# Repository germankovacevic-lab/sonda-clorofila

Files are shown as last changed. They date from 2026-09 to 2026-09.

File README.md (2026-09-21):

# Proyecto SONDA — Fluorómetro DIY de clorofila-a y turbidez

**Dossier constructivo · Copernicus · versión 2026-09**

## Qué es esto

Un instrumento de mesa, portátil y de bajo costo, que mide **clorofila-a** (indicador de algas/cianobacterias) y **turbidez** en muestras de agua. Se toma una muestra del espejo de agua con un frasco, se vuelca en una **cubeta de vidrio**, se mete la cubeta en el aparato, y en ~3 minutos el aparato escribe los resultados en una tarjeta SD.

El principio es **fluorometría**: la clorofila-a, iluminada con luz azul (~430 nm), re-emite luz roja (~680 nm). Un sensor espectral mide esa luz roja: a más clorofila, más señal. La turbidez se estima con un segundo LED infrarrojo y la luz que dispersan las partículas en suspensión.

## Para qué lo queremos

Copernicus monitorea espejos de agua por satélite (Sentinel-2). El satélite estima clorofila desde el espacio; este aparato nos da el **dato de verdad medido en el agua** para calibrar y validar esas estimaciones. No necesita ser un instrumento de laboratorio certificado: necesita ser **repetible y consistente**.

## Qué diseño replicamos

Este dossier NO es un diseño propio: es la guía en castellano para construir el
**DockEye** del COAST Lab (EE.UU.), un diseño abierto y publicado, usando de
manual complementario el **fluorómetro del ENSSAT** (Francia, escuela de
fotónica).

**DockEye viene incluido en este repo** (`vendor/DockEye/`, licencia MIT —
firmware en `vendor/DockEye/Firmware/`, y el set imprimible listo para usar
en [`planos/`](planos/): gabinete v9 + tapa). El ENSSAT, por su tamaño, se
descarga aparte:

```bash
./descargar-fuentes.sh   # clona ENSSAT en vendor/ pineado al commit de referencia
```

Commits de referencia usados para este dossier (2026-09-21):

- DockEye: `aea70d69787ee7859948dcfca584f06a7d0c6c92` (2025-07-14)
- ENSSAT: `876ba0dcd2a57655762b38ec11ed856d72429feb` (2025-07-17)

**Ante cualquier duda, la fuente manda**: el código, los STL y los README de
`vendor/DockEye/` son el original. Este dossier traduce, ordena y localiza
(componentes conseguibles en Argentina), pero no inventa nada. Donde la fuente
no es clara, el punto está marcado **A VERIFICAR**.

## Mapa del dossier

| Doc | Contenido |
|---|---|
| [01-lista-de-materiales.md](01-lista-de-materiales.md) | Todos los componentes: qué son, dónde conseguirlos en Argentina, sustitutos |
| [02-armado.md](02-armado.md) | Conexiones (tabla de pines), soldadura, impresión 3D, ensamble |
| [03-firmware.md](03-firmware.md) | Cómo cargar el programa al ESP32 y verificar que todo responde |
| [04-protocolo-de-uso.md](04-protocolo-de-uso.md) | Cómo medir: muestra, blanco, registro, calibración |
| [05-pruebas-de-aceptacion.md](05-pruebas-de-aceptacion.md) | Checklist de entrega: qué tiene que demostrar el aparato terminado |
| [06-videos-y-recursos.md](06-videos-y-recursos.md) | Videos y recursos de apoyo por habilidad; el armado de la unidad #1 será filmado |
| [planos/](planos/) | El set imprimible completo: **gabinete v9** (DockEye, MIT) + **tapa v1** (diseño: [Esteban Kovacevic](https://github.com/EstebanKovacevic), CC BY-SA) |

## Resumen del hardware (arquitectura)

```
                      ┌──────────────────────────┐
  USB-C / batería ───►│ ESP32-S3 (cerebro)       │
                      │  · corre el firmware     │
                      └────┬──────────┬──────────┘
                     I²C   │          │ I²C + SPI
              ┌────────────▼───┐  ┌───▼──────────────────┐
              │ AW9523         │  │ Adalogger            │
              │ driver de LEDs │  │ reloj (RTC) + SD     │
              └──┬─────────┬───┘  └──────────────────────┘
                 │         │
          LED azul       LED infrarrojo        ┌─────────────┐
          430 nm         910 nm                │ AS7341      │
             │              │                  │ sensor      │
             └──────► CUBETA ◄─── a 90° ──────►│ espectral   │
                    (vidrio, 10 mm)            └─────────────┘
                 dentro de gabinete impreso en 3D, oscuro
```

Todo va montado en el gabinete impreso en 3D de DockEye, que sostiene la cubeta
con los LEDs de un lado y el sensor **a 90 grados** (por eso la cubeta debe
tener las 4 caras transparentes).

## Presupuesto orientativo (2026-09, estimativo)

- **Vía local + sustitutos (ML/tiendas de electrónica):** ARS 150.000–280.000 aprox., según qué se consiga local y qué llegue de China por ML.
- **Vía importación de originales Adafruit (DigiKey/Mouser/courier):** ~USD 60–80 en partes + envío e impuestos; los LEDs Thorlabs originales suman ~USD 40–60 más.
- Detalle componente por componente en [01-lista-de-materiales.md](01-lista-de-materiales.md).

## Contacto técnico

Cualquier ambigüedad de la fuente está marcada **A VERIFICAR** en cada doc.
Antes de resolverla por las suyas, consultar con quien encargó el trabajo
(las decisiones de sustitución de componentes ópticos afectan la calibración).

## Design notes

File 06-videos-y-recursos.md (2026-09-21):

# 06 · Videos y recursos de apoyo

## ¿Hay video-tutorial del aparato?

**Todavía no — y va a haber.** Ni DockEye ni ENSSAT publicaron video de armado
(verificado 2026-09). Este dossier escrito es hoy la guía más completa que
existe del instrumento. **El armado de la primera unidad va a ser filmado y
publicado acá**, paso a paso, como video-tutorial completo en castellano.
Si estás construyendo y te trabás en un paso concreto, escribinos:
hola@copernicus.com.ar — lo destrabamos y de paso mejora el dossier.

## Recursos por habilidad

El armado no usa ninguna técnica exótica: se descompone en cuatro habilidades
estándar del mundo maker, cada una con muchísimo material en español. Por cada
una: una guía escrita de referencia + qué buscar en YouTube.

### 1. Soldar tiras de pines a los módulos
- Búsqueda YouTube: `como soldar pines header arduino`
- Es la soldadura más básica que existe (pin pasante, pad grande). Regla del
  doc 02: soldadura brillante y cónica, sin puentes entre pines vecinos.

### 2. Programar el ESP32 con Arduino IDE
- Guía escrita (referencia clásica en español): https://www.luisllamas.es/como-programar-esp32-con-el-ide-de-arduino/
- Curso Prometec (texto + video): https://www.prometec.net/02-instalando-el-entorno-arduino-y-el-pluggin-esp32/
- Búsqueda YouTube: `instalar ESP32 arduino IDE español`
- Después seguir el doc 03 de este dossier (tiene los pasos específicos).

### 3. Conectar módulos I²C (sensor, RTC, driver)
- Guía escrita: https://www.luisllamas.es/arduino-i2c/
- Búsqueda YouTube: `bus I2C arduino explicado español`
- Lo específico nuestro (qué pin va con qué) está en las tablas del doc 02 —
  no hace falta entender el protocolo, solo conectar según tabla.

### 4. Imprimir el gabinete 3D
- El set imprimible completo está en `planos/`: `gabinete-dockeye-v9.stl` + `tapa-v1.stl`.
- Búsqueda YouTube: `imprimir STL cura tutorial español`
- Sin impresora propia: cualquier servicio de impresión 3D lo cotiza con el
  STL (parámetros en el doc 02: PLA/PETG negro opaco, relleno ≥50%).

## Bibliografía del método (para quien quiera el fundamento)

- Leeuw, Boss & Wright (2013) — fluorómetro de fitoplancton con electrónica
  de bajo costo, validado contra instrumentos comerciales: doi:10.3390/s130607872
- Lopin (2024) — sensores AS726x/AS7341 para clorofila con regresión PLS:
  github.com/KyleLopin/asm_chloro_test

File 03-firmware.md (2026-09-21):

# 03 · Firmware: carga y verificación

> Fuente: `vendor/DockEye/Firmware/Open_Fluorometer/DockEye.ino` y
> `vendor/DockEye/Firmware/README.md`. El firmware es UN solo archivo .ino.

## 1. Qué hace el firmware (para entender qué esperar)

Al encender, el aparato ejecuta **una** secuencia completa y se queda quieto:

1. Inicializa sensor AS7341, RTC y driver AW9523. Si alguno no responde, **se frena** e imprime el error por el puerto serie.
2. Crea/abre `Test.csv` en la SD y escribe el encabezado.
3. Parpadea el LED indicador 2 veces → **fase clorofila**: enciende el LED azul 60 segundos, midiendo y grabando continuamente los 10 canales del sensor.
4. Parpadea 3 veces → **fase turbidez**: enciende el LED infrarrojo 60 segundos, ídem.
5. Escribe en la SD un bloque `SUMMARY` con: promedio F8 con LED azul, promedio F8 con LED IR (fondo), la resta, y la clorofila-a calibrada con la ecuación `chla = 0,1332 × diff − 1,7127` (⚠️ esa ecuación es la calibración del aparato de ELLOS: para el nuestro se reemplaza tras calibrar — doc 04).
6. Queda en bucle infinito hasta que se lo apague y prenda de nuevo.

Cada medición vuelca por el puerto serie (9600 baudios) una barra de progreso y los valores crudos: eso es lo que se usa para verificar.

## 2. Preparar el entorno (Arduino IDE en castellano)

1. Instalar **Arduino IDE 2.x** desde arduino.cc (Archivo → Preferencias → Idioma: Español).
2. Agregar soporte ESP32: Archivo → Preferencias → *URLs adicionales de gestor de placas*, pegar:
   `https://espressif.github.io/arduino-esp32/package_esp32_index.json`
3. Herramientas → Placa → Gestor de placas → buscar **esp32** (por Espressif Systems) → Instalar (versión 3.x).
4. Instalar librerías: Herramientas → Administrar bibliotecas, buscar e instalar:

| Librería | Autor | Nota |
|---|---|---|
| **Adafruit AS7341** | Adafruit | instala solas sus dependencias (BusIO, Sensor) — aceptar "Instalar todas" |
| **Adafruit AW9523** | Adafruit | solo si se usa el AW9523 |
| **RTClib** | Adafruit | maneja PCF8523 y DS3231 |
| **SdFat - Adafruit Fork** | Bill Greiman | ⚠️ elegir el **fork de Adafruit**, no el SdFat original |

   El repo no fija versiones exactas (**A VERIFICAR** solo si algo no compila: probar la última estable de cada una; el firmware es simple y usa APIs básicas).

5. Selección de placa:
   - Feather original: Herramientas → Placa → esp32 → **Adafruit Feather ESP32-S3 2MB PSRAM** (o la variante que corresponda al modelo comprado).
   - Devkit genérico: **ESP32S3 Dev Module**.
   - En ambos: `USB CDC On Boot: Enabled` (para que se vea el monitor serie por USB).

## 3. Ajustes al .ino según el hardware armado

Abrir `vendor/DockEye/Firmware/Open_Fluorometer/DockEye.ino` y guardarlo como copia de trabajo (ej. `firmware-sonda/sonda.ino` — no editar el vendor). Ajustes:

### 3.1 Si se armó la versión original (Feather+Adalogger+AW9523)
Nada que tocar. Flashear tal cual.

### 3.2 Si se usa RTC DS3231 en vez del Adalogger
```cpp
// línea 8:  RTC_PCF8523 rtc;   →
RTC_DS3231 rtc;
```
y más abajo, `rtc.initialized()` no existe para DS3231: reemplazar ese chequeo por `rtc.lostPower()`.

### 3.3 Si el CS de la microSD no es el pin 10
```cpp
// línea 20: const int SD_CHIP_SELECT = 10;  →
const int SD_CHIP_SELECT = <GPIO elegido>;
```

### 3.4 Si NO se usa AW9523 (LEDs por GPIO + transistor)
Hay que reemplazar el manejo de LEDs: quitar `Adafruit_AW9523.h`, el objeto `aw`, y las llamadas `aw.pinMode/aw.analogWrite`, por `pinMode(GPIO, OUTPUT)` y `digitalWrite(GPIO, HIGH/LOW)` sobre los GPIO elegidos para LED azul, LED IR y LED indicador. Son ~6 puntos de edición, todos evidentes buscando `aw.` en el archivo. Mantener la lógica idéntica (mismos tiempos, mismas fases).

### 3.5 Para uso en campo sin PC conectada
El `setup()` arranca con:
```cpp
while (!Serial) { delay(1); }
```
Eso **espera a que haya un monitor serie abierto**: conectado a un power bank, puede quedarse esperando para siempre. Para uso autónomo, comentar esas líneas (o encerrarlas en un timeout). **A VERIFICAR en banco**: probar el aparato con power bank y confirmar que arranca solo. Para todas las pruebas del doc 05, dejarlo como está (se trabaja con la PC conectada).

## 4. Flasheo

1. Conectar la placa por USB-C (cable de datos).
2. Seleccionar el puerto: Herramientas → Puerto (aparece al conectar; en Windows es COMx, en Mac /dev/cu.usbmodem…).
3. Botón **Subir** (flecha →). Si la placa no entra sola en modo de programación: mantener **BOOT**, tocar **RESET**, soltar BOOT, reintentar.
4. Éxito = "Hard resetting via RTS pin..." o similar, sin errores rojos.

## 5. Primera verificación (con el monitor serie)

Herramientas → Monitor Serie, **9600 baudios**. Apretar RESET en la placa. Debe verse, en orden:

1. Ningún mensaje de error. Los errores posibles y su significado:
   - `Could not find AS7341` → revisar cableado I²C del sensor (SDA/SCL invertidos es el clásico) o dirección.
   - `Couldn't find RTC` → cableado I²C del RTC o pila faltante.
   - `AW9523 not found? Check wiring!` → ídem para el driver.
   - `Error opening file!` → SD ausente, mal formateada (usar FAT32) o CS incorrecto.
2. `AW9523 found!` (si aplica).
3. `Begin chlorophyll measurements.` + LED azul encendido (se ve por la ranura de la cubeta si la tapa está abierta) + barra de progreso `Chlorophyll-a: [###...] 42%` + líneas `Raw F8: <número>`.
4. Al minuto: `End chlorophyll measurements.` → `Begin turbidity measurements.` + LED IR encendido (⚠️ el IR es invisible al ojo; se ve **con la cámara del celular**, que lo capta violáceo) + líneas `Raw NIR: <número>`.
5. Al final: bloque `==== FINAL AVERAGE RESULTS ====` con los promedios.

6. Apagar, sacar la microSD, abrirla en la PC: debe existir `Test.csv` con encabezado, ~2 minutos de filas de datos y el bloque `SUMMARY` al final. ⚠️ El firmware **agrega** al mismo `Test.csv` en cada corrida: para cada ensayo nuevo conviene borrar o renombrar el archivo previo.

## 6. Ajuste del RTC (fecha y hora)

El firmware original **no pone en hora el RTC** (solo avisa si no corre). Para ponerlo en hora una única vez: cargar el ejemplo `RTClib → pcf8523` (o `ds3231`) del IDE, que ajusta el reloj a la hora de compilación, y después volver a flashear el firmware de la sonda. Con la pila puesta, la hora se conserva.

## 7. Parámetros del sensor (no tocar sin motivo)

El firmware fija: `ATIME=255`, `ASTEP=999`, ganancia `256X` → tiempo de integración ≈ 0,7 s por lectura. Son los valores con los que DockEye calibró. Si el sensor **satura** (valores clavados en 65535) o queda sin señal, se ajusta la ganancia — pero eso invalida comparaciones con datos previos: anotar SIEMPRE cualquier cambio en la hoja del instrumento (el CSV graba ATIME/ASTEP/GAIN en cada fila, lo que permite auditar).

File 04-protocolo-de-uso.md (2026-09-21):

# 04 · Protocolo de uso y calibración

> Fuente: procedimiento de extracción y estándares de
> `vendor/DockEye/Procedures/Chlorophyll a extraction/README.md`, guía de
> calibración de `vendor/Chlorophyll-Fluorometer/calibration.md` (ENSSAT) y
> scripts de `vendor/DockEye/Data Analysis/`.
>
> Este doc lo usa quien opere el instrumento. El constructor solo necesita
> entenderlo por arriba + ejecutar las pruebas del doc 05.

## 1. Regla de oro

**Cubetas de VIDRIO o CUARZO, nunca plástico.** Los estándares de calibración
van en acetona al 80%, que disuelve el plástico. Y una cubeta atacada por
solvente queda opaca → basura. Todas las cubetas del kit son de vidrio/cuarzo
con 4 caras transparentes.

## 2. Medición de rutina (muestra de campo)

### 2.1 Toma de muestra
1. Tomar agua sub-superficial (~20–30 cm de profundidad) del espejo de agua, en frasco limpio y opaco o envuelto (la clorofila se degrada con luz y calor).
2. Rotular: fecha, hora, punto GPS, quién.
3. Medir lo antes posible (ideal < 2 h; mantener fresco y a oscuras hasta medir).

### 2.2 Medición
1. Homogeneizar la muestra (invertir el frasco suavemente 10 veces; no agitar violento, hace burbujas).
2. Enjuagar la cubeta 2 veces con la propia muestra; llenar a ~3/4. **Sin burbujas** en las caras ópticas; secar el exterior con papel suave (huellas y gotas desvían luz).
3. Insertar la cubeta en el gabinete, cerrar la tapa.
4. Encender el aparato (o RESET). Corre solo: 2 parpadeos → 60 s de LED azul → 3 parpadeos → 60 s de LED IR → resumen. Total ~2,5 min.
5. Apagar, retirar cubeta, enjuagar con agua destilada.

### 2.3 Blanco
En cada tanda de mediciones (mínimo al inicio y al final), correr una medición
idéntica con **agua destilada**. Ese valor es el cero del día y baja junto con
los datos.

### 2.4 Registro
- Los datos quedan en `Test.csv` de la microSD. **Renombrar el archivo tras cada corrida** (ej. `2026-09-21_laguna-X_p1.csv`), porque el firmware agrega al mismo archivo.
- Llevar planilla paralela: fecha/hora, punto, blanco del día, archivo asociado, observaciones (color del agua, clima).
- El valor que interesa: en el bloque `SUMMARY`, la resta `Chl − Turb F8` (señal de fluorescencia corregida por fondo) y la `Calibrated Chlorophyll-a` **solo si ya se cargó nuestra ecuación de calibración** (ver §3.4).

## 3. Calibración (resumen)

La calibración convierte "cuentas" del sensor en µg/L. Se hace al construir el
aparato, y se repite si se cambia cualquier componente óptico o parámetro del
sensor.

### 3.1 Preparar extracto de clorofila (fuente: espinaca)
Del procedimiento DockEye:
1. Picar y pesar ~4 g de hojas de espinaca fresca.
2. Moler en mortero con 5–10 mL de acetona fría hasta que no queden trozos visibles.
3. Pasar a frasco de vidrio ámbar con 20 mL de acetona al 80%.
4. Sonicar 30 min en baño de hielo (si no hay sonicador: **A VERIFICAR** — DockEye no da alternativa; en la práctica reposo prolongado en frío y oscuridad extrae igual, con menor eficiencia).
5. Centrifugar 5 min a 3000 rpm (o dejar decantar y filtrar) y quedarse con el líquido claro (sobrenadante).
6. La concentración real del extracto madre se determina contra un instrumento de referencia (laboratorio o fluorómetro comercial). **Este paso requiere un tercero con instrumento calibrado** — es el único eslabón que no se resuelve con el kit.

### 3.2 Estándares
Diluir en acetona al 80% para obtener 5 puntos: **100, 50, 20, 10 y 5 µg/L**
(cada uno se logra diluyendo el anterior: 2×, 2,5×, 2×, 2×).

### 3.3 Medir la curva
1. Medir blanco (acetona 80% sola).
2. Medir cada estándar de menor a mayor concentración, con el protocolo normal (§2.2), enjuagando la cubeta con el estándar siguiente entre puntos.
3. En planilla (Excel/LibreOffice): graficar señal (promedio F8 con LED azul, menos fondo) vs. concentración. Ajustar recta: `señal = a × concentración + b`. Debe dar R² > 0,95; si no, revisar burbujas, luz externa, cubeta sucia.

### 3.4 Cargar la calibración al firmware
Invertir la recta y reemplazar en el .ino (línea ~114):
```cpp
float calibrated_chla = 0.1332 * diff - 1.7127;  // ← ecuación de DockEye, NO la nuestra
```
por los coeficientes propios (`chla = (diff − b) / a`). Anotar fecha de
calibración y coeficientes en la hoja del instrumento. Re-flashear.

> Nota: los números 0,1332 y −1,7127 que trae el código son la calibración del
> prototipo de COAST-Lab. **Sin recalibrar, las lecturas "calibradas" de nuestro
> aparato no son confiables** — sí lo son las cuentas crudas y sus diferencias.

### 3.5 Turbidez
DockEye no publica protocolo de calibración de turbidez (el canal NIR se usa
sobre todo como fondo para la clorofila). Si se quiere turbidez en NTU:
calibrar con estándares de formazina o suspensiones caseras validadas —
**A VERIFICAR / fase 2**, no bloquea la entrega.

## 4. Mantenimiento

- Cubetas: lavar con agua destilada tras cada uso; guardar secas y envueltas. Nunca cepillar por dentro con nada abrasivo.
- No dejar muestras/estándares dentro del aparato.
- Acetona: manipular con ventilación, lejos de fuentes de calor; guardar en frasco de vidrio rotulado.
- Revisar cada tanto que el gabinete siga sellado a la luz (prueba de linterna del doc 02 §5).

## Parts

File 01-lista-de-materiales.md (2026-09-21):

# 01 · Lista de materiales (BOM)

> Precios y disponibilidad **verificados 2026-09-21** publicación por publicación
> en MercadoLibre Argentina (sesión en vivo). Donde dice "verificado" es el precio
> de un listing concreto de ese día. Los part numbers del diseño original salen
> del README de `vendor/DockEye/`.
>
> Regla general: **el sensor AS7341 y el conjunto óptico son el corazón del
> instrumento — no escatimar ahí.** En el resto (micro, SD, RTC, cables) los
> genéricos sirven perfecto.

## A. Electrónica principal

### A1. Microcontrolador — ESP32-S3

- **Función:** cerebro del aparato; corre el firmware, habla con los sensores, escribe la SD.
- **Original:** Adafruit ESP32-S3 Feather (Adafruit **#5477**, ~USD 17,50 en adafruit.com).
- **En Argentina:** el Feather original de Adafruit **no se consigue local** (ML solo trae otros Feather a >$190.000). Lo que sí abunda:
  - Placa genérica **ESP32-S3 DevKitC / NodeMCU ESP32-S3** (WROOM-1, USB-C) — verificado 2026-09-21: **$18.644** (listing "Placa De Desarrollo Esp32 S3 N16r8 Wifi Bluetooth 2 Usb-c", stock local, llega hoy) · alternativa **$20.990** ("Nodemcu ESP32 S3 44 Pines Usb C", HobbyTronica 4.9, local).
- **Sustituto aceptable:** SÍ, cualquier devkit ESP32-S3 con USB nativo.
  - *Qué se pierde:* el formato Feather (el gabinete STL de DockEye está pensado para apilar Feather + Adalogger; con un devkit genérico la electrónica va montada aparte, ver 02-armado) y el cargador de batería LiPo integrado (se reemplaza con un power bank USB).
  - *Qué NO se pierde:* nada eléctrico. El firmware usa I²C + SPI estándar; el fabricante del original avisa que solo probó el S3 MINI-1, así que **cualquier variante requiere la prueba de humo del doc 05 igual**.
- ⚠️ El firmware original usa el pin **10** como chip-select de la SD; en un devkit genérico elegir un GPIO libre y ajustar una línea del firmware (ver 03-firmware).

### A2. Datalogger — RTC + ranura microSD

- **Función:** reloj de tiempo real (fecha/hora de cada medición) + tarjeta SD donde queda el CSV con los datos.
- **Original:** Adafruit Adalogger FeatherWing (Adafruit **#2922**): RTC **PCF8523** + slot microSD, se apila sobre el Feather.
- **En Argentina:** no se consigue local. Sustituto de dos módulos, ambos ubicuos en ML:
  - **Módulo lector microSD SPI** (genérico) — verificado 2026-09-21: **$2.799** (listing "Modulo Lector De Tarjetas Micro Sd" UNIBOT, local, llega hoy) · $3.059 Starwarecomar · $4.999 HobbyTronica.
  - **Módulo RTC DS3231** (I²C, con pila) — verificado 2026-09-21: **$6.999** (listing "Modulo Rtc Ds3231 Alta Precision Eeprom 24c32 c/pila", HobbyTronica 4.9, local, llega hoy) · $5.399 Educabot (sin confirmar pila).
- **Sustituto aceptable:** SÍ, con un cambio de UNA línea en el firmware: `RTC_PCF8523` → `RTC_DS3231` (la librería RTClib soporta ambos; ver 03-firmware). El DS3231 es incluso más preciso que el PCF8523.
- También: **tarjeta microSD** clase 10, 8–32 GB (ARS 8.000–15.000, cualquier marca conocida).

### A3. Driver de LEDs — AW9523

- **Función:** expansor I²C de 16 pines que enciende/apaga y regula los LEDs con corriente constante, comandado por el ESP32. El firmware original lo usa tal cual (`Adafruit_AW9523`).
- **Original:** Adafruit AW9523 breakout (Adafruit **#4886**, ~USD 4,95).
- **En Argentina:** **NO se consigue** — re-verificado 2026-09-21: la búsqueda "aw9523" en ML devuelve 84 resultados pero **ninguno es el chip** (todo repuestos de notebook y herramientas). Ausencia confirmada. Opciones:
  1. **Importarlo** (Adafruit/DigiKey/Mouser, o pedido puntual a importador tipo CDR Electrónica, cdronline.com.ar — cotizan a pedido). Es chico y barato: conviene sumarlo al mismo pedido que cualquier otra cosa que se importe. **← Recomendado: mantiene el firmware original sin tocar.**
  2. **Sustituto local:** manejar cada LED directo desde un GPIO del ESP32 con un transistor NPN (2N2222/PN2222, <ARS 1.000) + resistencia limitadora — es exactamente lo que hace el diseño ENSSAT (`vendor/Chlorophyll-Fluorometer/hardware/components.md`).
     - *Qué se pierde:* la regulación de corriente constante del AW9523 (la intensidad del LED queda atada a la estabilidad de la fuente → algo más de deriva entre mediciones) y hay que **modificar el firmware** (reemplazar las llamadas `aw.analogWrite(...)` por control de GPIO; ver 03-firmware). Para un instrumento que se calibra contra estándares, es tolerable, pero la opción 1 es más fiel al original.

### A4. Sensor espectral — AS7341 ⭐ (el corazón, sin sustituto)

- **Función:** sensor de 11 canales que mide la luz por bandas: el canal **F8 (680 nm)** capta la fluorescencia de la clorofila y el canal **NIR (910 nm)** la dispersión por turbidez.
- **Original:** Adafruit AS7341 breakout (Adafruit **#4698**, ~USD 15,95).
- **En Argentina — verificado 2026-09-21:** SÍ hay, casi todo envío internacional desde China (2–4 semanas):
  - **$19.752** (listing "Módulo Sensor As7341 11 Canales For Medición", China) · $18.076 ("Módulo Sensor Del Espectrómetro De Color Visible", China).
  - Clon del breakout Adafruit ("As7341 Sensor De Luz De 10 Canales Placa Divisora Stemma"): **$22.665–24.276** (China).
  - Única opción aparentemente con stock local: "As7341 Módulo De Sensor De Espectrómetro" a **$139.998** (6 cuotas, envío gratis) — solo si el plazo de China es inaceptable.
- **Sustituto aceptable: NO.** Todo el firmware y la calibración de DockEye dependen de este chip exacto. Cualquier módulo que traiga el chip **AS7341** sirve (el chip es el mismo AMS); lo que cambia entre módulos es solo el conector.
- ⚠️ Comprar **dos** si el presupuesto lo permite: es el componente más difícil de reponer rápido si uno viene fallado.

### A5. LED de excitación azul — 430 nm

- **Función:** ilumina la muestra para excitar la clorofila-a (pico de absorción ~430 nm).
- **Original:** Thorlabs **LED430L** (LED 430 nm, encapsulado 5 mm, ~USD 40–60 + envío internacional caro — Thorlabs no vende barato ni rápido a Argentina).
- **En Argentina:**
  - **Elumiled** — verificado 2026-09-21: **$5.603/u** (listing "Led 3w Azul 420-430nm Epileds Estrella Predisipadora Elumiled", local) · x2 $8.810 · x5 $18.434. Ojo: es formato **estrella 3 W con predisipadora**, no 5 mm — en ML no apareció 430 nm en encapsulado 5 mm; el estrella funciona (más potencia, requiere limitar corriente y adaptar la montura del gabinete). **← Primera opción.**
  - Fallback azul royal — verificado 2026-09-21: **$8.590 x10** ("X10 Led Epiled Azul Profundo 440nm 3 Watts", local, llega mañana) · 10 W 445–450 nm $14.999.
- **Sustituto aceptable:** SÍ, con matices:
  - Un 425–435 nm local (Elumiled) es sustituto pleno: misma zona de excitación.
  - Un 445–450 nm también **funciona** (la clorofila absorbe fuerte en toda esa banda) pero con eficiencia de excitación algo menor → menos señal → la pendiente de calibración cambia. **No es problema porque cada aparato se calibra individualmente** (doc 04), pero hay que anotar la longitud de onda usada en la hoja del instrumento.
  - ⚠️ NO usar LED "azul común" sin especificación (suelen ser 465–470 nm, ya lejos del pico).
- **A VERIFICAR al comprar:** que el datasheet/publicación declare la longitud de onda dominante.

### A6. LED infrarrojo — 910 nm

- **Función:** ilumina la muestra en infrarrojo; las partículas en suspensión dispersan esa luz hacia el sensor → estimación de turbidez (y de fondo para restar a la señal de clorofila).
- **Original:** Thorlabs **LED910L** (910 nm, 5 mm).
- **En Argentina:** los IR de 5 mm ubicuos son de **940 nm** — verificado 2026-09-21: **$2.080 x5** (listing "X5 Led 5mm Infrarrojo Ir-led Emisor 940nm", local, llega mañana) · x10 $6.460 Htec, llega hoy. ⚠️ En la misma búsqueda hay **fototransistores/receptores** 940 nm al mismo precio: comprar el **EMISOR**.
- **Sustituto aceptable:** SÍ — LED IR **940 nm** ó **850 nm** de 5 mm.
  - *Qué se pierde:* el canal NIR del AS7341 está centrado en 910 nm; a 940 nm el sensor lo ve con menos sensibilidad (a 850 nm también, del otro lado). Menos señal de turbidez → se compensa en calibración. **A VERIFICAR** en banco: que con agua turbia (unas gotas de leche en agua) el canal NIR responda claramente sobre el fondo (prueba incluida en doc 05).

### A7. Pasivos y conexión

| Ítem | Para qué | Dónde / precio aprox. |
|---|---|---|
| Protoboard 830 pts + 40 cables dupont | montar módulos y LEDs | verificado 2026-09-21: $17.637 (kit, local) |
| Cables dupont M-H x40 30 cm | conexiones I²C y alimentación | verificado 2026-09-21: $4.133 (CANDYHO, local) |
| Tiras de pines macho + hembra | soldar a los módulos | ARS 1.000–3.000 |
| Resistencias (kit x100 metal film 1% 1/4 W, 10 valores) | limitadora de LEDs (si no se usa AW9523) | verificado 2026-09-21: $4.500 (Micro Minds, local, llega hoy) |
| Transistores PN2222A | driver de LED alternativo (solo opción A3-2) | verificado 2026-09-21: $2.840 x10 ("Kit X10 Pn2222a", local, llega mañana) |
| Cable USB-C **de datos** | flasheo y alimentación | ARS 4.000–10.000 (verificar que sea de datos, no solo carga) |
| Power bank USB 5 V | uso en campo sin PC | ARS 20.000–40.000 (opcional) |

## B. Óptica y muestras

### B1. Cubetas — VIDRIO o CUARZO, 4 caras transparentes ⭐

- **Función:** contienen la muestra. El LED entra por una cara y el sensor mira por la cara **a 90°** → las **4 caras deben ser transparentes** (las cubetas de espectrofotómetro comunes tienen solo 2 caras pulidas: **NO sirven**).
- **Material: vidrio o cuarzo, NUNCA plástico.** La calibración usa acetona (disuelve el plástico) y los solventes arruinan la cubeta y contaminan la muestra.
- **Original:** cubetas de vidrio para fluorometría, paso óptico 10 mm (DockEye las compra en Amazon, baratas).
- **En Argentina — verificado 2026-09-21:** todo envío internacional China (2–4 sem.):
  - **$17.377 el pack de 4** (listing "4 Celdas Cúbicas De Cuarzo 3.5ml 10mm", China) — mejor valor: cubre blanco + muestra + 2 repuestos en una compra.
  - Packs de 2: $18.678–24.633 ("Pack De 2 Cubetas De Cuarzo Ópticas 10mm").
  - (Proveedores locales de laboratorio tipo Instrumental Pasteur: ~ARS 197.000 la pieza — evitar salvo urgencia.)
- **A VERIFICAR al comprar:** confirmar con el vendedor que las 4 caras son pulidas/transparentes ("cubeta para **fluorescencia**", no "para espectrofotómetro"). Comprar **al menos 4** (blanco, muestra, repuesto x2).

### B2. Consumibles de calibración

(los usa quien calibra, no necesariamente el constructor — ver doc 04)

| Ítem | Para qué | Dónde |
|---|---|---|
| Acetona pura (p.a. o al menos >99%) | extracción de clorofila y estándares | ⚠️ verificado 2026-09-21: en ML solo hay removedores cosméticos con acetona — la p.a. **se compra en droguería física** (Cicarelli/local), ~ARS 8.000–20.000/litro |
| Alcohol etílico 96% (alternativa de extracción) | extracción de clorofila | verificado 2026-09-21: $18.600 bidón 5 L ("Alcohol Etilico 96% Bidon 5 Litros", local, llega hoy) |
| Agua destilada | blancos y diluciones | ferretería/farmacia, ARS 2.000–5.000 x5 L |
| Espinaca fresca | fuente de clorofila para estándares | verdulería 🙂 |
| Frascos de vidrio color ámbar | los extractos se degradan con luz | verificado 2026-09-21: $13.775 x10 gotero 30 cc ámbar ("Frasco Gotero Vidrio Ambar C/pipeta 30cc Pack X 10u", local, llega hoy) |
| Jeringas descartables 10 ml | trasvase y dosificación | verificado 2026-09-21: $17.640 x100 ("Jeringas Descartable 10cc Pico Liso X 100", Gauss Bioingeniería, local) — alcanza un pack chico de farmacia |

## C. Mecánica

### C1. Gabinete impreso en 3D

- **Original:** [`planos/gabinete-dockeye-v9.stl`](planos/gabinete-dockeye-v9.stl) (la **v9** de DockEye, la más reciente; iteraciones anteriores en `vendor/DockEye/Hardware/Housing/`). Sostiene la cubeta, los LEDs y el sensor en la geometría de 90° correcta y bloquea la luz ambiente.
- **Impresión:** PLA o PETG **NEGRO opaco** (crítico: el gabinete es la cámara oscura del instrumento), relleno ≥50% en la zona óptica (criterio tomado del manual ENSSAT). Verificado 2026-09-21: los servicios de impresión 3D en ML publican **"precio a convenir"** (se cotiza con el STL en mano) — hay varios en CABA/GBA, incluido **"Delta 3D Lab" en Tigre**. Referencia de insumo: filamento PLA negro $18.990/kg (Hellbot, local) → una pieza de ~100 g debería rondar **ARS 15.000–30.000**, a confirmar cotizando con el STL.
- ⚠️ **La tapa solo está como `Open-Fluorometer-Lid v2.f3d`** (archivo Fusion 360, no STL). **A VERIFICAR:** exportar el STL desde Fusion 360 (gratis para uso personal) o resolver una tapa simple equivalente (una placa opaca que cierre bien a la luz). 
- **El gabinete se imprime en 3D, sin excepción** (decisión de proyecto 2026-09-21): es LO que garantiza la geometría LED-cubeta-sensor y es la parte fácil/barata (servicio de impresión). Sin impresora propia, mandar a imprimir el STL.

### C2. Tornillería y varios

- Tornillos M2.5/M3 con tuercas (fijar placas al gabinete): ARS 3.000–5.000 el surtido.
- Cinta aisladora negra / silicona negra: sellar fugas de luz.
- **A VERIFICAR:** el repo DockEye no publica el listado exacto de tornillería ("hardware for assembling the sensor", sin detalle) — resolver en el momento con el gabinete impreso en mano.

## Resumen de compra — dos caminos

**Camino 1 — “fiel al original” (recomendado si hay tiempo):**
importar de Adafruit/DigiKey: ESP32-S3 Feather #5477 + Adalogger #2922 + AW9523 #4886 + AS7341 #4698 (~USD 50 en partes + envío/impuestos) y LEDs locales (Elumiled 430 nm + IR 940 nm). Firmware original casi sin tocar.

**Camino 2 — “todo local/ML” (más rápido, más barato):**
ESP32-S3 devkit genérico + módulo microSD + RTC DS3231 + módulo AS7341 (China por ML) + LEDs locales + transistores. Requiere los ajustes de firmware del doc 03 (CS de SD, RTC, driver de LEDs).

### Costo total consolidado (verificado 2026-09-21, listings concretos de ML)

| Rubro | Verificado |
|---|---|
| ESP32-S3 devkit (local) | $18.644 |
| Módulo microSD SPI (local) | $2.799 |
| RTC DS3231 c/pila (local) | $6.999 |
| AS7341 (China, 2–4 sem.) | $19.752 |
| LED azul Elumiled 420–430 nm x2 (local) | $8.810 |
| LED IR 940 nm 5 mm x5 (local) | $2.080 |
| PN2222 x10 + kit resistencias x100 (local) | $7.340 |
| Protoboard 830 + cables dupont (local) | $21.770 |
| Cubetas cuarzo 10 mm x4 (China, 2–4 sem.) | $17.377 |
| Impresión 3D gabinete (a convenir, ref. ~100 g) | ~$15.000–30.000 |
| Varios no verificados (pines, microSD card, cable USB-C, tornillería) | ~$20.000–30.000 |

- **Escenario 1 — armado mínimo (1 sensor):** **~ARS 150.000–165.000**.
- **Escenario 2 — recomendado (2º AS7341 de respaldo):** **~ARS 170.000–185.000**.
- **Escenario 3 — sin esperar China (AS7341 "local" a $139.998 + cubetas China igual):** **~ARS 270.000–285.000** — solo pagar la prisa si hay una demo con fecha.
- Consumibles de calibración (alcohol 96% + frascos ámbar + jeringas, todo ML local): **~ARS 50.000** aparte; la acetona p.a. va por droguería física.

**Qué domina la incertidumbre:** (1) la **impresión 3D** — único rubro sin precio publicado, se cotiza con el STL; (2) el **AS7341 y las cubetas** — precio firme pero plazo China 2–4 semanas y riesgo aduana; todo el resto es stock local con entrega en 24 h. El rango viejo estimado (150–280 mil) queda **confirmado en su piso**: la compra real da ~$150–185 mil.

| Componente | ¿Se consigue en Argentina? (verificado 2026-09-21) | Sustituto |
|---|---|---|
| ESP32-S3 | ✅ local $18.644, llega hoy | devkit genérico |
| Adalogger (RTC+SD) | ❌ | microSD SPI $2.799 + DS3231 $6.999 (local) |
| AW9523 | ❌ ausencia re-confirmada | importar ó GPIO+transistor |
| AS7341 | ✅ ML China $19.752 (2–4 sem.) · "local" $139.998 | **no hay sustituto** |
| LED 430 nm | ⚠️ Elumiled 420–430 nm estrella 3 W $5.603 (no hay 5 mm) | sí, con nota de calibración |
| LED 910 nm | ⚠️ solo 940 nm: x5 $2.080 | sí, validar en banco |
| Cubetas cuarzo 4 caras | ✅ ML China: x4 $17.377 (2–4 sem.) | ninguno (nunca plástico) |
| Gabinete 3D | ✅ servicio, precio a convenir (~$15–30 mil) | — (sin plan B: se imprime sí o sí) |

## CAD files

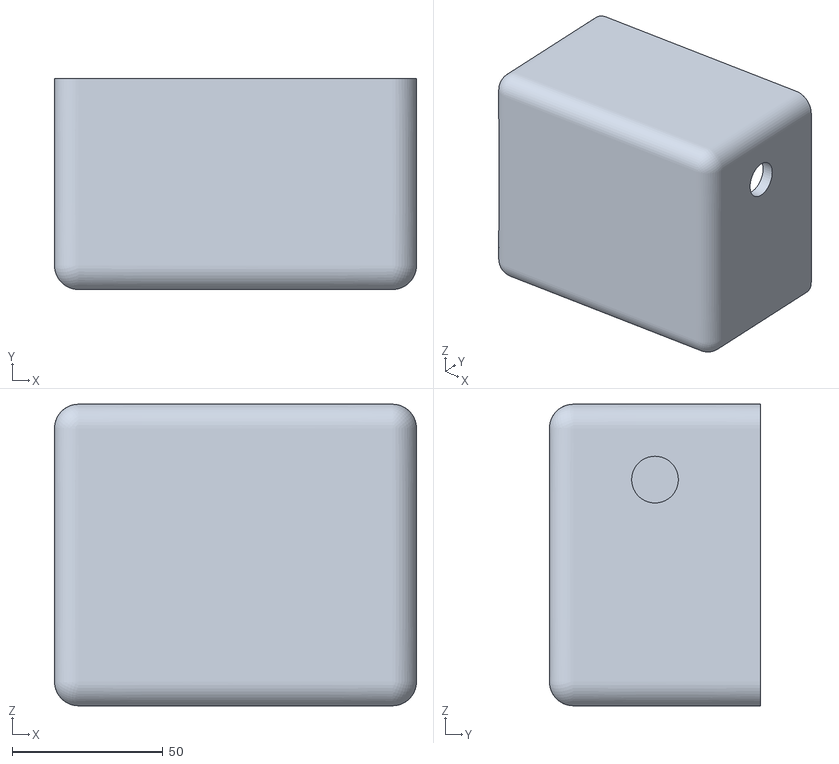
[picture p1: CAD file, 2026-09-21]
planos/gabinete-dockeye-v9.stl
120.0 x 70.0 x 100.0

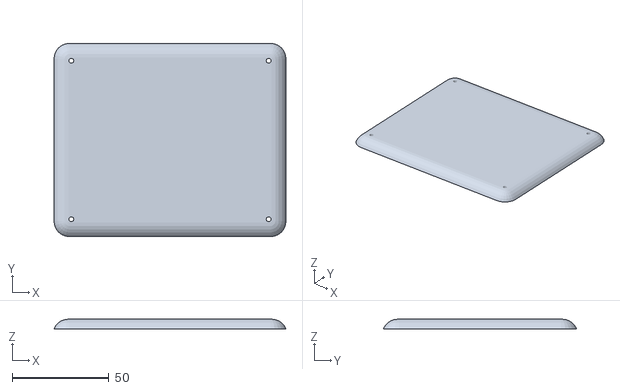
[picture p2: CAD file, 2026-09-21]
planos/tapa-v1.stl
120.0 x 100.0 x 5.00

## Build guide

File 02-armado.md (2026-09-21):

# 02 · Guía de armado

> Fuente: README de `vendor/DockEye/` (sección *Wiring Instructions*) + firmware
> `vendor/DockEye/Firmware/Open_Fluorometer/DockEye.ino` + manual de ensamble de
> `vendor/Chlorophyll-Fluorometer/` (ENSSAT) como referencia de buenas prácticas.
>
> El original advierte: *"Instructions for mounting the LEDs and light sensor to
> the cuvette holder will be added soon"* — es decir, **el propio repo DockEye no
> documenta el montaje óptico fino**; esa parte acá está resuelta con criterio
> propio y marcada A VERIFICAR donde corresponde.

## 0. Principio a respetar SIEMPRE

La geometría óptica es el instrumento:

- LED(s) apuntando a una cara de la cubeta.
- Sensor AS7341 mirando la cara **a 90°** (nunca enfrentado al LED: se satura).
- Todo dentro del gabinete **cerrado y opaco** (cámara oscura).

Cualquier luz ambiente que se cuele o cualquier corrimiento mecánico entre
mediciones arruina la repetibilidad.

## 1. Soldadura de módulos

Para cada módulo (ESP32, AS7341, AW9523/driver, RTC, microSD): soldar las tiras
de pines que vienen incluidas. Reglas:

1. Pines macho hacia abajo para pinchar en protoboard (o hembra según el plan de montaje).
2. Soldadura brillante y cónica en cada pin; sin puentes entre pines vecinos.
3. Si se usa el sandwich original Feather + Adalogger: al Feather pines macho, al Adalogger **pines apilables (stacking)**, y el Adalogger se enchufa arriba del Feather (así lo indica el README de DockEye).

## 2. Conexionado eléctrico

Todos los sensores hablan **I²C**: comparten los mismos dos cables (SDA y SCL)
en paralelo, más alimentación. La microSD habla **SPI** (4 cables propios).

### 2.1 Tabla de conexiones — versión original (Feather + Adalogger + AW9523)

Del README de DockEye:

| Desde | Pin | Hacia | Pin |
|---|---|---|---|
| Protoboard riel **+** | — | ESP32-S3 | 3.3V |
| Protoboard riel **−** | — | ESP32-S3 | GND |
| AW9523 | VIN | riel + | |
| AW9523 | GND | riel − | |
| AW9523 | SCL | ESP32-S3 | SCL |
| AW9523 | SDA | ESP32-S3 | SDA |
| AS7341 | VIN | riel + | |
| AS7341 | GND | riel − | |
| AS7341 | SCL | ESP32-S3 | SCL |
| AS7341 | SDA | ESP32-S3 | SDA |
| **LED azul 430 nm** | ánodo (+) | riel + | |
| LED azul 430 nm | cátodo (−) | AW9523 | **pin 10** |
| **LED IR 910 nm** | ánodo (+) | riel + | |
| LED IR 910 nm | cátodo (−) | AW9523 | **pin 0** |

- El Adalogger (RTC + SD) no lleva cables: se **apila** sobre el Feather. El firmware espera la SD en chip-select **10** (constante `SD_CHIP_SELECT = 10` del .ino), que es el CS del Adalogger apilado.
- El AW9523 en modo LED actúa de sumidero de corriente constante (~37 mA por pin): por eso los LEDs van del riel + al pin del AW9523, **sin resistencia**.
- El firmware además maneja un **LED en el pin 3 del AW9523 como indicador** (parpadea para marcar inicio/fin de cada fase; función `blinkLED`). El README de wiring no lo menciona. **A VERIFICAR / decisión práctica:** conectar un LED común (cualquier color) + al riel +, − al pin 3 del AW9523, montado visible en el gabinete. Si no se conecta, el aparato funciona igual pero sin señal visual de progreso.
- Direcciones I²C que espera el firmware: AS7341 en `0x39`, AW9523 en `0x58` (defaults de ambos módulos; no tocar jumpers de dirección).

### 2.2 Tabla de conexiones — versión "todo local" (devkit ESP32-S3 + módulos sueltos)

Si se arma con sustitutos (ver doc 01), el mapa equivalente:

| Módulo | Pin módulo | ESP32-S3 devkit |
|---|---|---|
| AS7341 | VIN / VCC | 3V3 |
| AS7341 | GND | GND |
| AS7341 | SDA | GPIO 8 (o el SDA que se configure) |
| AS7341 | SCL | GPIO 9 (o el SCL que se configure) |
| RTC DS3231 | VCC / GND / SDA / SCL | 3V3 / GND / mismos SDA y SCL |
| microSD SPI | VCC | 3V3 (⚠️ verificar que el módulo sea de 3.3 V o tenga regulador) |
| microSD SPI | CS | GPIO libre (anotar; se pone en el firmware) |
| microSD SPI | SCK / MOSI / MISO | SPI del devkit (GPIO 12 / 11 / 13 típico en S3) |
| LED azul | ánodo | 3V3 vía resistencia limitadora* |
| LED azul | cátodo | colector del transistor PN2222 (emisor a GND, base a un GPIO vía 1 kΩ) |
| LED IR | ídem con segundo transistor y GPIO propio | |

\* Calcular la resistencia según el LED: R = (3,3 V − Vf) / I. Ej.: LED azul Vf≈3,0 V a 20 mA → R ≈ 15 Ω (redondear a 22 Ω comercial y medir). Para el IR Vf≈1,4 V a 20 mA → R ≈ 100 Ω.

⚠️ Los GPIO exactos del devkit dependen del modelo comprado. Regla: **elegirlos, anotarlos en la hoja del instrumento y ajustarlos en el firmware** (doc 03). No hay valores "mágicos": lo que importa es la consistencia.

## 3. Impresión 3D y ensamble mecánico

### 3.1 Qué imprimir

Las dos piezas están juntas en [`planos/`](planos/):

- **[`planos/gabinete-dockeye-v9.stl`](planos/gabinete-dockeye-v9.stl)** — cuerpo principal (portacubeta + posiciones de LEDs y sensor). Es la v9 de DockEye, la última versión (el original y sus iteraciones v7/v8 están en `vendor/DockEye/Hardware/Housing/`).
- **Tapa: RESUELTA — usar [`planos/tapa-v1.stl`](planos/tapa-v1.stl) de este repo.** Diseño original de [Esteban Kovacevic](https://github.com/EstebanKovacevic) (CC BY-SA 4.0), creado porque la tapa de DockEye solo existe como `.f3d` de Fusion 360 y no se podía imprimir tal como estaba.

Parámetros: PLA o PETG **negro opaco**, relleno ≥50%, capa 0,2 mm. Verificar a contraluz que las paredes no transluzcan; si transluce, pintar de negro por dentro o subir perímetros.

### 3.2 Ensamble óptico

1. Insertar el **AS7341** en su alojamiento del gabinete, con la ventana del sensor mirando al hueco de la cubeta. Fijar con tornillos M2.5 o una gota de silicona en las esquinas de la placa (nunca sobre la ventana óptica).
2. Insertar los **dos LEDs** en sus alojamientos (a 90° del sensor). Los LEDs de 5 mm entran a presión en agujeros de 5 mm; asegurar con silicona por atrás.
3. Probar que la **cubeta** entra y sale sin forzar y siempre en la misma posición (el gabinete DockEye está diseñado para cubeta estándar de 10 mm).
4. Pasar el cableado por detrás y cerrar. Sellar cualquier rendija con cinta negra.

**A VERIFICAR:** la orientación exacta de LEDs/sensor dentro del gabinete v9 no está documentada en el repo (las instrucciones de montaje óptico "se agregarán pronto" según el README). Con la pieza impresa en mano es autoevidente dónde va cada cosa (los alojamientos tienen las formas de los componentes); si no lo fuera, consultar antes de pegar nada.

### 3.3 Electrónica en el gabinete

- Versión original Feather: el sandwich Feather+Adalogger va fijado dentro/junto al gabinete según el espacio de la v9.
- Versión devkit: montar protoboard/perforada en una caja auxiliar pegada al gabinete óptico, con los cables de LEDs y sensor entrando por un pasacables sellado a la luz.

## 4. Impresión 3D: sin plan B

El gabinete se imprime en 3D, sin excepción (decisión de proyecto, 2026-09-21): el
STL de DockEye ya trae el portacubeta y los alojamientos ópticos a 90° resueltos —
es la parte fácil y la que garantiza la geometría. No improvisar gabinetes
artesanales.

## 5. Checklist de fin de armado

- [ ] Soldaduras inspeccionadas (sin puentes, sin pines fríos).
- [ ] Continuidad verificada con téster: 3V3→VIN de cada módulo, GND común.
- [ ] Ningún corto entre + y − (téster en continuidad sobre los rieles, debe dar abierto).
- [ ] LEDs con polaridad correcta (pata larga = ánodo = +).
- [ ] Cubeta entra/sale suave y repetible.
- [ ] Gabinete cerrado no deja pasar luz (mirar en cuarto oscuro con linterna por fuera).

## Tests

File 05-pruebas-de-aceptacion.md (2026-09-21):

# 05 · Pruebas de aceptación

Checklist que el constructor ejecuta y documenta ANTES de entregar el aparato.
Se entrega junto con el instrumento:

- esta lista tildada, con los valores medidos anotados,
- los archivos CSV de cada prueba (renombrados como se indica),
- la "hoja del instrumento": componentes usados (con longitudes de onda de los
  LEDs compradas), GPIO elegidos, y toda desviación respecto del diseño original.

Materiales para las pruebas: PC con monitor serie, agua destilada, leche (unas
gotas, para simular turbidez), las cubetas del kit, linterna.

## P1 — Inspección y encendido

- [ ] **P1.1** Inspección visual: soldaduras sin puentes, polaridad de LEDs correcta, cables firmes.
- [ ] **P1.2** Sin cortos: téster en continuidad entre 3V3 y GND da abierto.
- [ ] **P1.3** Conectado por USB, la placa enciende y el puerto serie aparece en el IDE.
- [ ] **P1.4** Al resetear, el monitor serie (9600 baudios) NO muestra ninguno de los errores (`Could not find AS7341`, `Couldn't find RTC`, `AW9523 not found`, `Error opening file!`). → Los tres periféricos I²C y la SD responden.

## P2 — Fecha y hora

- [ ] **P2.1** El RTC está en hora (ver doc 03 §6). Las filas del CSV muestran fecha/hora actual real, no 2000-01-01.
- [ ] **P2.2** Desconectar TODO 10 minutos, volver a encender: la hora sigue bien (la pila del RTC funciona).

## P3 — Respuesta de los LEDs

- [ ] **P3.1** Durante la fase clorofila se ve el LED azul encendido (tapa abierta, cubeta afuera).
- [ ] **P3.2** Durante la fase turbidez, la cámara del celular ve el LED IR encendido.
- [ ] **P3.3** El LED indicador (si se montó) parpadea 2 veces al inicio, entre fases y al final.

## P4 — El sensor ve los LEDs (prueba de canal)

Con cubeta llena de **agua destilada**, gabinete cerrado, correr una medición completa y abrir el CSV:

- [ ] **P4.1** Durante la fase clorofila (filas "Chlorophyll-a"), el canal **F1 (415 nm, primera columna de cuentas)** registra valores claramente mayores que con el aparato apagado → el sensor está viendo el LED azul (por dispersión residual). *Si F1 está clavado en 65535, hay demasiada luz directa: revisar geometría.*
- [ ] **P4.2** Durante la fase turbidez (filas "Turbidity"), el canal **NIR (última columna)** sube respecto del fondo.
- [ ] **P4.3** Ningún canal clavado en 65535 (saturación) ni todo en 0 (sensor tapado / LED muerto) durante las dos fases.

Guardar como `P4_agua-destilada.csv`.

## P5 — Oscuridad (sellado del gabinete)

- [ ] **P5.1** Prueba de linterna: en cuarto oscuro, linterna barriendo el gabinete cerrado por fuera; los valores del serie no se mueven apreciablemente.
- [ ] **P5.2** Medición con cubeta de agua destilada en cuarto iluminado vs. cuarto oscuro: los promedios F8 del SUMMARY difieren menos de 5%. Guardar ambos CSV (`P5_luz.csv`, `P5_oscuro.csv`).

## P6 — Respuesta a turbidez (prueba funcional del canal IR)

1. Medir agua destilada (ya hecho en P4).
2. Agregar 2–3 gotas de leche a la cubeta, mezclar, medir de nuevo.

- [ ] **P6.1** El promedio NIR de la fase turbidez con leche es **claramente mayor** (al menos 2×) que con agua destilada. → El LED IR sustituto (940/850 nm) alcanza; si la diferencia es marginal, escalar: probar más corriente de LED o cambiar a un IR de mayor potencia, y anotarlo.

Guardar `P6_leche.csv`.

## P7 — Respuesta a clorofila (prueba funcional del canal azul)

Sin estándares de laboratorio, alcanza una fuente casera de clorofila: licuar
unas hojas de espinaca en un poco de alcohol o agua, filtrar con filtro de café,
diluir hasta color verde apenas perceptible.

- [ ] **P7.1** El promedio F8 de la fase clorofila con el extracto diluido es claramente mayor que con agua destilada.
- [ ] **P7.2** Una dilución al medio del mismo extracto da señal intermedia (entre el extracto y el blanco). → El aparato ordena concentraciones correctamente.

Guardar `P7_extracto.csv` y `P7_extracto-diluido.csv`.

> Nota: esto NO es la calibración (doc 04, la hace el operador con estándares).
> Es solo la demostración de que el canal de clorofila responde y es monótono.

## P8 — Repetibilidad (la prueba que más importa)

Con la MISMA cubeta de agua destilada, **5 mediciones completas seguidas**,
sacando y volviendo a insertar la cubeta entre cada una:

- [ ] **P8.1** Coeficiente de variación del promedio F8 (desvío estándar / media) **< 5%** entre las 5 corridas.
- [ ] **P8.2** Repetir con el extracto de espinaca diluido: CV < 5%.

Si falla: casi siempre es mecánico (la cubeta no asienta igual, el gabinete
filtra luz, un LED flojo). No se entrega hasta que pase.

Guardar los 10 CSV como `P8_rep_blanco_1..5.csv` y `P8_rep_extracto_1..5.csv`.

## P9 — Autonomía (si se va a usar a batería)

- [ ] **P9.1** Con power bank y SIN PC conectada, el aparato completa una medición solo (ver doc 03 §3.5 — hay que haber quitado la espera del puerto serie) y el CSV queda bien escrito.

*(Opcional si el uso previsto es siempre con notebook al lado — dejarlo asentado.)*

## P10 — Entrega

- [ ] **P10.1** Hoja del instrumento completa (componentes, λ de los LEDs, GPIO, desviaciones, fecha).
- [ ] **P10.2** Todos los CSV de pruebas en una carpeta/pendrive o subidos donde se indique.
- [ ] **P10.3** El .ino final exacto que quedó flasheado (archivo, no captura).
- [ ] **P10.4** Kit completo: aparato, cubetas (mínimo 4), cable USB, microSD, fuente/power bank si se incluyó.

---

**Criterio de aceptación global:** P1–P8 todas tildadas con evidencia. P9 según
modalidad de uso. Cualquier ítem no cumplido se entrega declarado, no oculto.

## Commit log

2026-09-21 Dossier constructivo: fluorómetro DIY de clorofila-a y turbidez (réplica DockEye, docs en castellano)
2026-09-21 README: fuentes vía script pineado + nota de licencias
2026-09-21 Doc 06: videos y recursos por habilidad + anuncio de filmación de la unidad #1
2026-09-21 planos/tapa-v1.stl: tapa imprimible, diseño original de Esteban Kovacevic (CC BY-SA) — resuelve el .f3d de DockEye
    [tapa-v1.stl]
2026-09-21 planos/: set imprimible completo — gabinete DockEye v9 (MIT) junto a la tapa v1
    [gabinete-dockeye-v9.stl]
2026-09-21 Apuntar al set imprimible de planos/ desde README y lista de materiales
2026-10-26 Firmware 2026: DockEye_050226 con medición de fondo discreta (issue COAST-Lab/DockEye#11)
    - vendor/DockEye re-pineado aea70d6 → 0eb9500: firmware estable nuevo,
    datos de calibración 2025-2026 del lab, scripts MATLAB, rediseño de
    gabinete (aún sin documentar; el dossier sigue sobre v9)
    - Doc 03: secuencia nueva (fondo a oscuras → azul → IR, ~3 min), RTC
    auto-ajustado, CSV por día, ecuaciones nuevas
    - Docs 02/04/05: indicador sin parpadeos, fases y archivo del día
    - Contexto: COAST-Lab usaba este firmware hace meses; el original tenía
    un bug en la lógica de fondo (respuesta de Adam Lucas en el issue #11)
2026-10-26 Doc 01: la tapa ya está resuelta en planos/tapa-v1.stl — quitar A VERIFICAR viejo
